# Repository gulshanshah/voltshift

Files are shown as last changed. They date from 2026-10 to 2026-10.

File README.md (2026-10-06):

# VoltShift

**Automatic voltage-stable line switcher.**

In many villages and homes the supply arrives unbalanced — some lines sit weak,
some sit high, and people walk over to the board and move the home supply to the
line that behaves. VoltShift does that switching automatically: it watches three
incoming lines, picks the one that is stable near 240 V, and drives a selector
switch onto it with a stepper motor — or to OFF when no line is safe.

## Repository layout

| Path | What it is |
| --- | --- |
| `pcb/` | KiCad 9 project — `voltshift.kicad_pro`, schematic, board and netlist |
| `firmware/` | ATmega328P firmware (bare-metal C, PlatformIO) |
| `media/` | Board renders, layer plots, schematic SVG and PDF |
| `docs/` | Schematic PDF and the ERC report |

## How it works

1. **Sensing** — three identical channels (R, Y, B), each a fusible 4R7 input
   resistor, three 150k 1 % series resistors stepping the AC line down, and a
   1N4007 rectifier turning it into a DC level the MCU can read. A 4k7 shunt,
   a 5.6 V zener and a 47 µF cap clamp and smooth that level.
2. **Isolation** — each channel feeds a PC817 optocoupler, so the mains domain
   stays galvanically separate from the logic domain; the opto output lands on
   an ATmega328P ADC input through a 10k pull-down.
3. **Decision** — the MCU samples all three inputs continuously, accepts only a
   line that reads stable near 240 V, and rejects anything too high or too low.
4. **Switching** — a 28BYJ-48 stepper driven by a ULN2003A turns the selector
   through four 45° positions: the healthy line, or OFF when nothing is in
   range.

The board keeps manual switching out of the equation — the home supply always
lands on the healthiest voltage.

## Hardware

- **MCU** — ATmega328P-PU @ 16 MHz, with ISP (2×3) and 5 V TTL UART headers
- **Drive** — ULN2003A → 28BYJ-48 stepper selector
- **Sensing** — 3× opto-isolated AC channels → ADC0/1/2
- **Power** — external 5 V DC input, ferrite-isolated AVCC
- **Board** — 170 × 100 mm, 2-layer, mains domain and logic domain split with
  ≥ 6 mm creepage between them and a ground pour kept to the logic side only
- **Status** — schematic and routed PCB complete, ERC clean (0 errors,
  0 warnings)

### Safety

This board handles **240 VAC mains**. Sense resistors must be rated for the
working voltage, creepage/clearance must be respected, and the board must not
be touched while powered. It is a prototype — validate it against your local
electrical rules before putting it anywhere near a real installation.

## Media

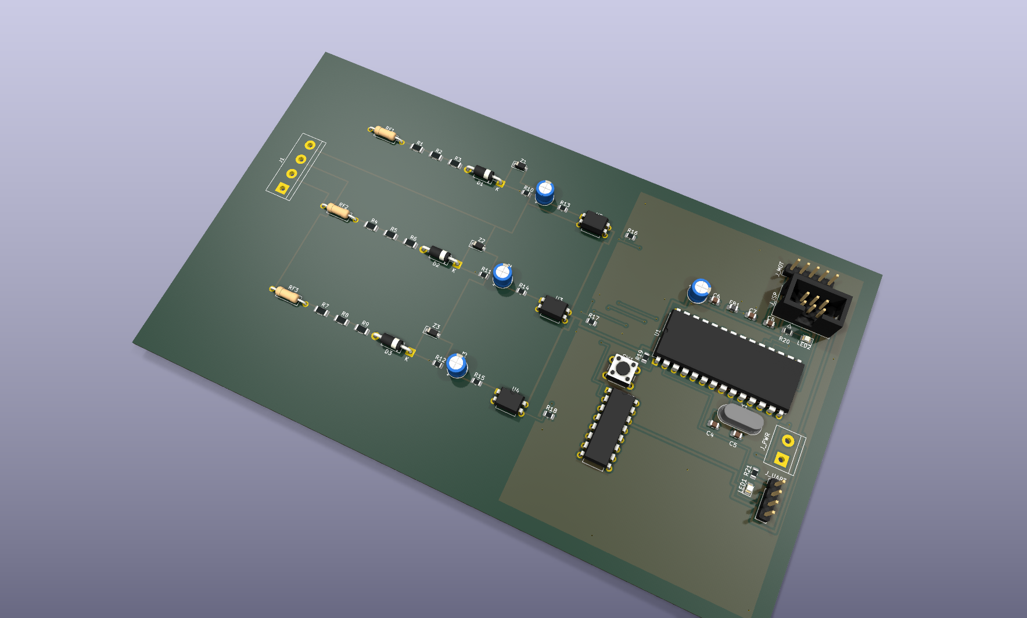
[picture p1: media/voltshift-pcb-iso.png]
VoltShift board render


| Top | Bottom |
| --- | --- |
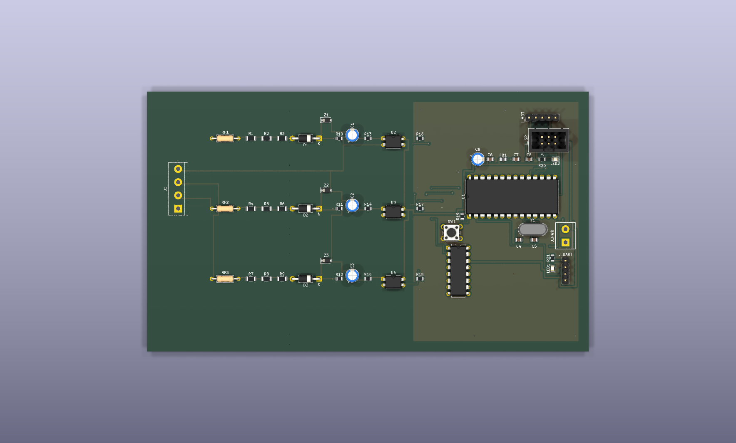
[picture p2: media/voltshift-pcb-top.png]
Board top
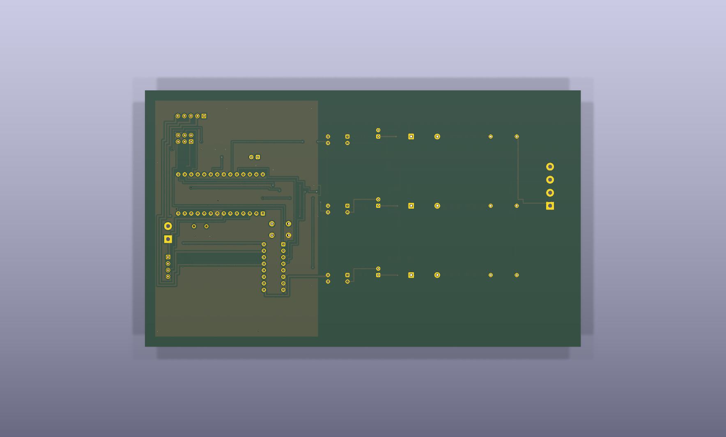
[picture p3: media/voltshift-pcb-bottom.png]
Board bottom
|  |  |

- [Schematic (SVG)](media/voltshift.svg) · [Schematic (PDF)](media/voltshift-schematic.pdf)
- [Top copper layout](media/voltshift-layout-top.svg) · [Bottom copper layout](media/voltshift-layout-bottom.svg)

## Firmware

The firmware lives in `firmware/` and runs directly on the ATmega328P — no Arduino framework, no communication, fully automatic, about 1.8 KB of flash.

```
firmware/include/config.h   # thresholds, calibration, pin map, timing
firmware/src/adc.c           # averaged ADC reads + counts-to-decivolts calibration
firmware/src/selector.c      # line validity, best-line choice, hysteresis
firmware/src/stepper.c       # half-step driver for the 28BYJ-48 selector
firmware/src/led.c           # status LED patterns
firmware/src/main.c          # 1 ms tick, sample/evaluate loop, watchdog
```

Every 10 ms each channel is averaged and converted to decivolts; every 100 ms a line is accepted only if it sits inside 205.0–255.0 V with under 2.0 V of ripple. The selector moves to the accepted line closest to 240 V, only after that line beats the held one by more than 3 V for four consecutive evaluations, and drops to OFF the moment the held line goes invalid. The status LED reports state: slow blink while starting up, solid on a line, fast blink on OFF or while the motor is moving.

Build and flash with PlatformIO:

```
cd firmware
pio run                     # builds firmware.elf / firmware.hex
pio run -t upload           # default programmer is usbasp (ISP)
```

Calibration is per-channel in `include/config.h` — `VS_CAL_OFFSET_*` and `VS_CAL_SPAN_*_PER_100V` map raw ADC counts to voltage; tune them against a known-good meter before trusting the decisions.

## Working on the design

Open `pcb/voltshift.kicad_pro` in KiCad 9 and edit the schematic and the board
directly. Run the Electrical Rules Checker after any change — the last check
came back clean (0 errors, 0 warnings).

Keep the two domains apart while editing: mains circuitry stays left of the
isolation gap, the ground pour belongs to the logic side only, and the 6 mm
creepage between them must survive any move. The exported schematic PDF and
the ERC report are in `docs/`.

## Status

Schematic and PCB are done and ERC-clean, and the firmware builds for the
ATmega328P. Next up: fab the board and build the first unit.

## License

MIT — see [LICENSE](LICENSE).

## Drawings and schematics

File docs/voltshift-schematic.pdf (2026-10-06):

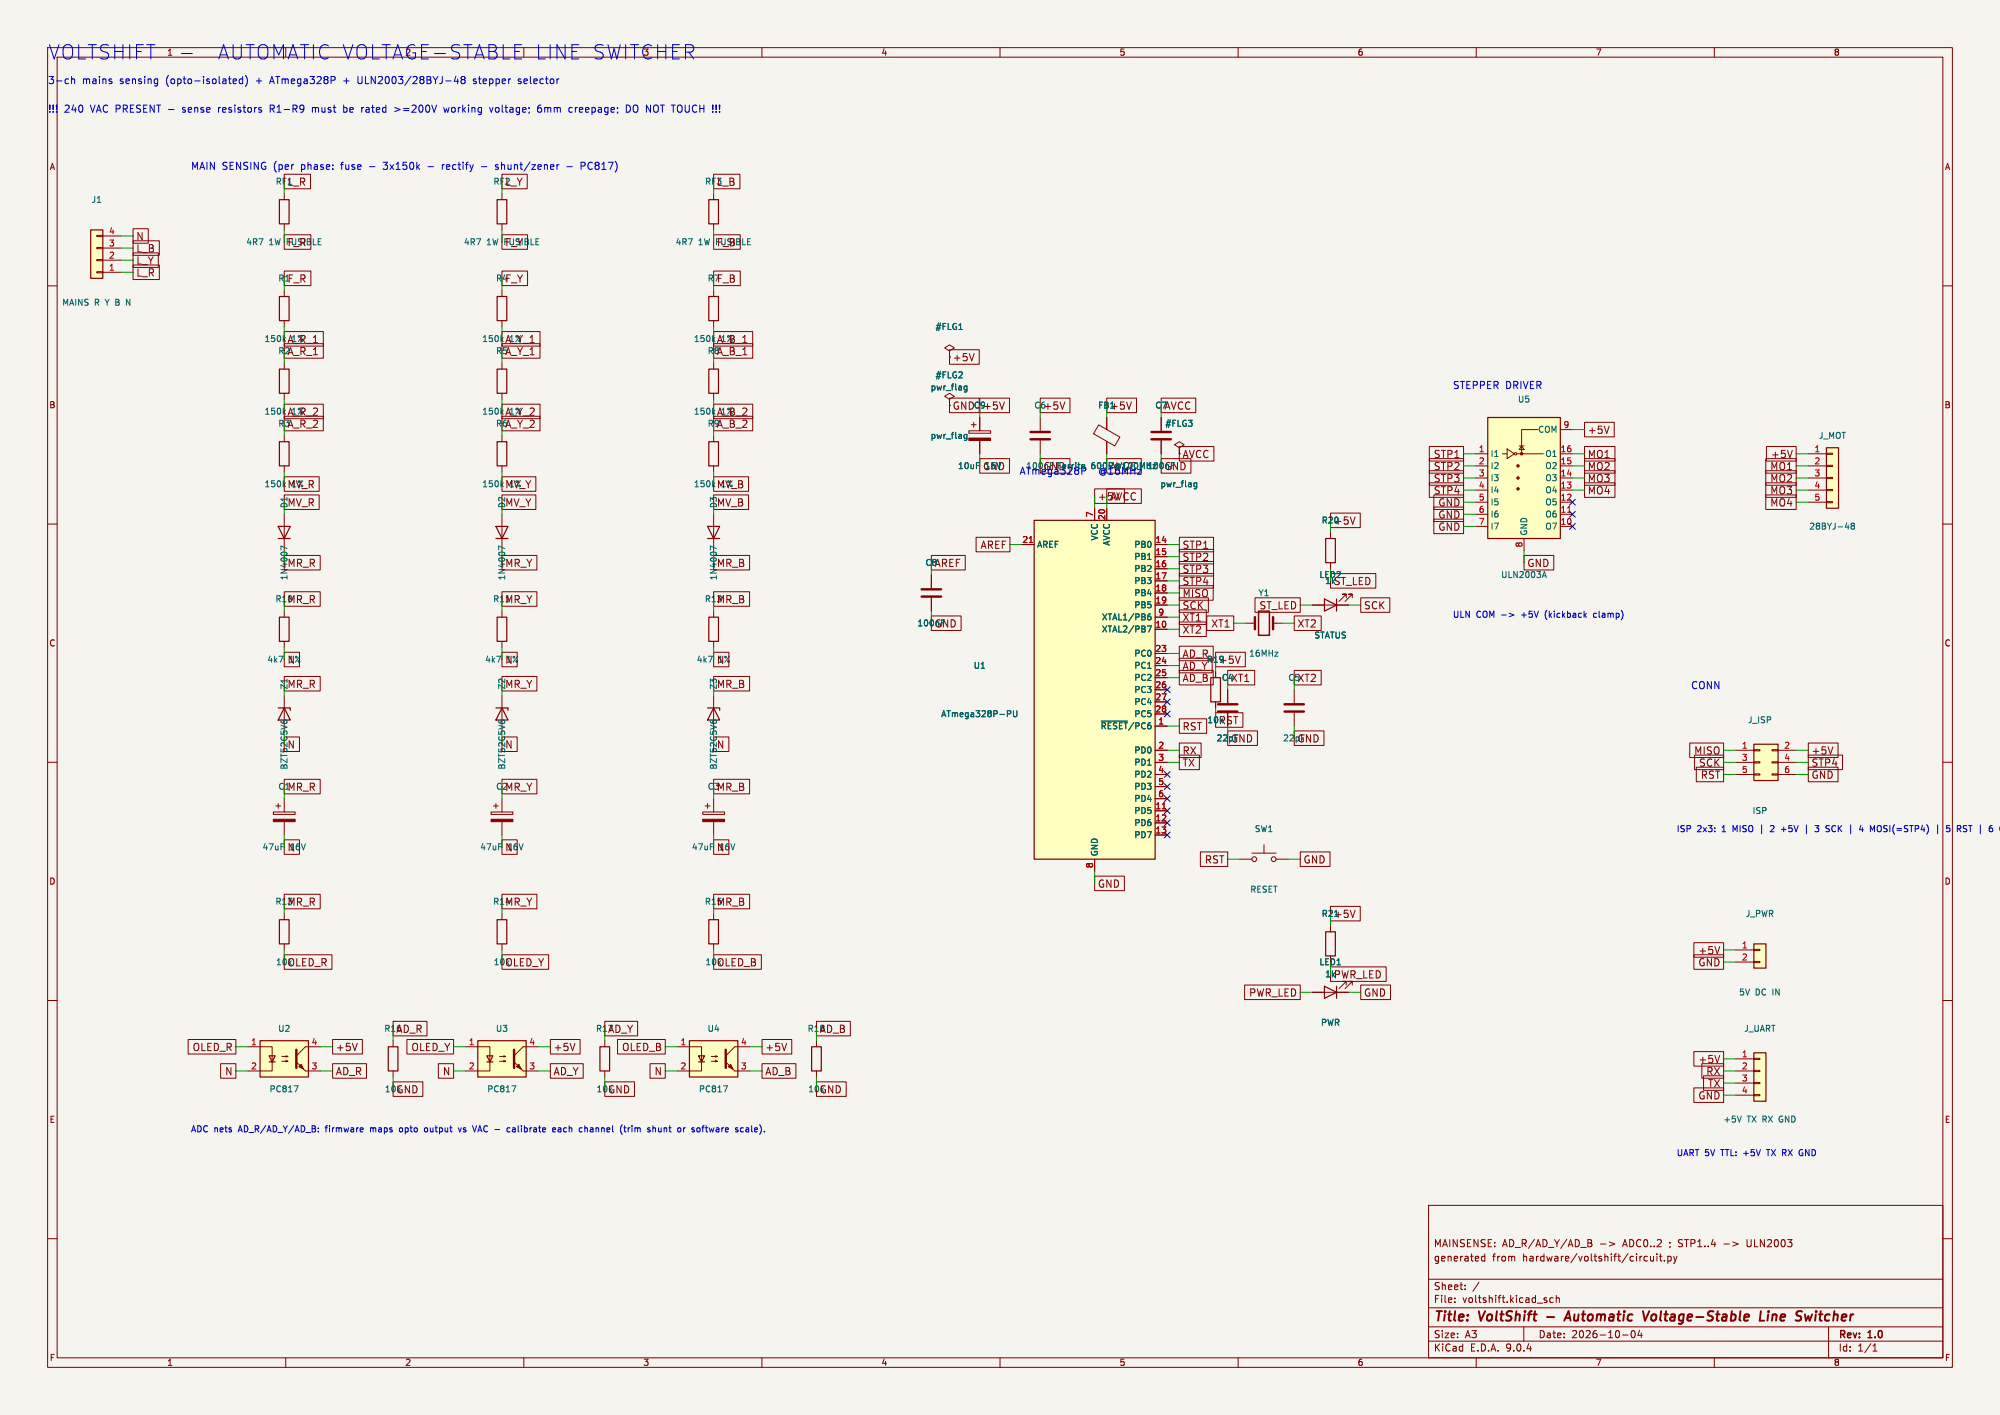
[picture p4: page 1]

UART 5V TTL: +5V TX RX GND

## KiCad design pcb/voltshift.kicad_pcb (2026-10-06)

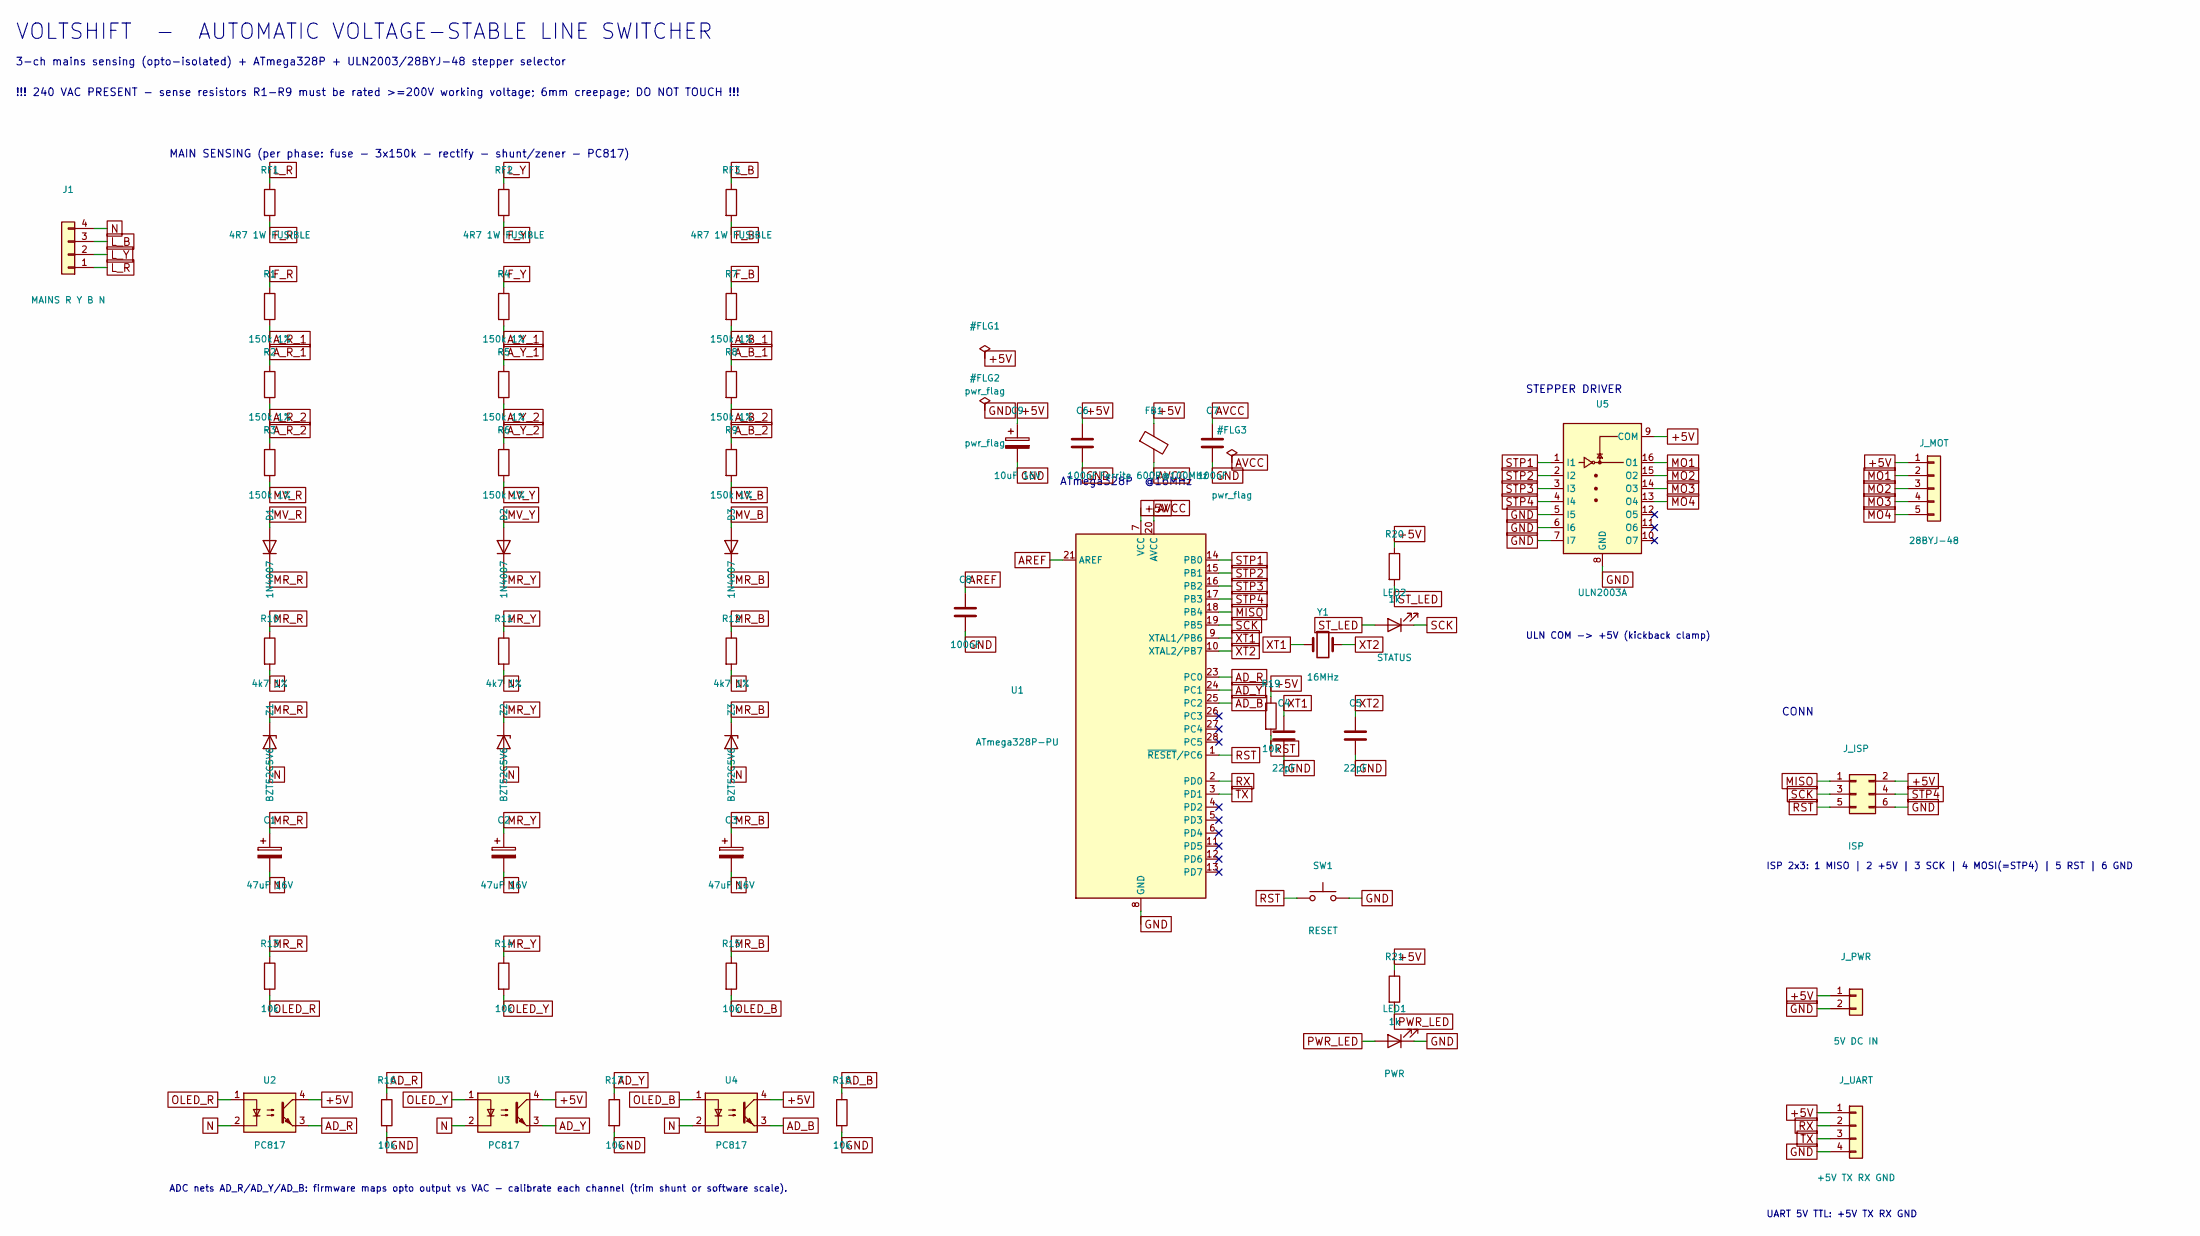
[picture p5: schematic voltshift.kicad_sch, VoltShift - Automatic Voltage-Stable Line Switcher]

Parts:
C1, C2, C3: 47uF 16V; CP_Radial_D5.0mm_P2.50mm
C4, C5: 22pF; C_0805_2012Metric
C6, C7, C8: 100nF; C_0805_2012Metric
C9: 10uF 16V; CP_Radial_D5.0mm_P2.50mm
D1, D2, D3: 1N4007; D_DO-41_SOD81_P10.16mm_Horizontal
FB1: Ferrite 600R@100MHz; L_0805_2012Metric
J1: MAINS R Y B N; TerminalBlock_bornier-4_P5.08mm
J_ISP: ISP; IDC-Header_2x03_P2.54mm_Vertical
J_MOT: 28BYJ-48; PinHeader_1x05_P2.54mm_Vertical
J_PWR: 5V DC IN; TerminalBlock_bornier-2_P5.08mm
J_UART: +5V TX RX GND; PinHeader_1x04_P2.54mm_Vertical
LED1: PWR; LED_0805_2012Metric
LED2: STATUS; LED_0805_2012Metric
R1, R2, R3, R4, R5, R6, R7, R8, R9: 150k 1%; R_1206_3216Metric
R10, R11, R12: 4k7 1%; R_0805_2012Metric
R13, R14, R15, R16, R17, R18, R19: 10k; R_0805_2012Metric
R20, R21: 1k; R_0805_2012Metric
RF1, RF2, RF3: 4R7 1W FUSIBLE; R_Axial_DIN0207_L6.3mm_D2.5mm_P10.16mm_Horizontal
SW1: RESET; SW_PUSH_6mm
U1: ATmega328P-PU; DIP-28_W15.24mm
U2, U3, U4: PC817; DIP-4_W7.62mm
U5: ULN2003A; DIP-16_W7.62mm
Y1: 16MHz; Crystal_HC49-4H_Vertical
Z1, Z2, Z3: BZT52C5V6; D_SOD-123

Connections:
+5V: C6.1, C9.1, FB1.1, J_ISP.2, J_MOT.1, J_PWR.1, J_UART.1, R19.1, R20.1, R21.1, U1.7 (VCC), U2.4, U3.4, U4.4, U5.9 (COM)
AD_B: R18.1, U1.25 (PC2), U4.3
AD_R: R16.1, U1.23 (PC0), U2.3
AD_Y: R17.1, U1.24 (PC1), U3.3
AREF: C8.1, U1.21 (AREF)
AVCC: C7.1, FB1.2, U1.20 (AVCC)
A_B_1: R7.2, R8.1
A_B_2: R8.2, R9.1
A_R_1: R1.2, R2.1
A_R_2: R2.2, R3.1
A_Y_1: R4.2, R5.1
A_Y_2: R5.2, R6.1
F_B: R7.1, RF3.2
F_R: R1.1, RF1.2
F_Y: R4.1, RF2.2
GND: C4.2, C5.2, C6.2, C7.2, C8.2, C9.2, J_ISP.6, J_PWR.2, J_UART.4, LED1.1 (K), R16.2, R17.2, R18.2, SW1.2, U1.8 (GND), U1.22 (GND), U5.5 (I5), U5.6 (I6), U5.7 (I7), U5.8 (GND)
L_B: J1.3, RF3.1
L_R: J1.1, RF1.1
L_Y: J1.2, RF2.1
MISO: J_ISP.1, U1.18 (PB4)
MO1: J_MOT.2, U5.16 (O1)
MO2: J_MOT.3, U5.15 (O2)
MO3: J_MOT.4, U5.14 (O3)
MO4: J_MOT.5, U5.13 (O4)
MR_B: C3.1, D3.1 (K), R12.1, R15.1, Z3.1 (K)
MR_R: C1.1, D1.1 (K), R10.1, R13.1, Z1.1 (K)
MR_Y: C2.1, D2.1 (K), R11.1, R14.1, Z2.1 (K)
MV_B: D3.2 (A), R9.2
MV_R: D1.2 (A), R3.2
MV_Y: D2.2 (A), R6.2
N: C1.2, C2.2, C3.2, J1.4, R10.2, R11.2, R12.2, U2.2, U3.2, U4.2, Z1.2 (A), Z2.2 (A), Z3.2 (A)
OLED_B: R15.2, U4.1
OLED_R: R13.2, U2.1
OLED_Y: R14.2, U3.1
PWR_LED: LED1.2 (A), R21.2
RST: J_ISP.5, R19.2, SW1.1, U1.1 (~RESET/PC6)
RX: J_UART.2, U1.2 (PD0)
SCK: J_ISP.3, LED2.1 (K), U1.19 (PB5)
STP1: U1.14 (PB0), U5.1 (I1)
STP2: U1.15 (PB1), U5.2 (I2)
STP3: U1.16 (PB2), U5.3 (I3)
STP4: J_ISP.4, U1.17 (PB3), U5.4 (I4)
ST_LED: LED2.2 (A), R20.2
TX: J_UART.3, U1.3 (PD1)
XT1: C4.1, U1.9 (XTAL1/PB6), Y1.1
XT2: C5.1, U1.10 (XTAL2/PB7), Y1.2

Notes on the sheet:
VOLTSHIFT - AUTOMATIC VOLTAGE-STABLE LINE SWITCHER
3-ch mains sensing (opto-isolated) + ATmega328P + ULN2003/28BYJ-48 stepper selector
!!! 240 VAC PRESENT - sense resistors R1-R9 must be rated >=200V working voltage; 6mm creepage; DO NOT TOUCH !!!
MAIN SENSING (per phase: fuse - 3x150k - rectify - shunt/zener - PC817)
ATmega328P @16MHz
STEPPER DRIVER
CONN
ADC nets AD_R/AD_Y/AD_B: firmware maps opto output vs VAC - calibrate each channel (trim shunt or software scale).
ISP 2x3: 1 MISO | 2 +5V | 3 SCK | 4 MOSI(=STP4) | 5 RST | 6 GND
UART 5V TTL: +5V TX RX GND
ULN COM -> +5V (kickback clamp)

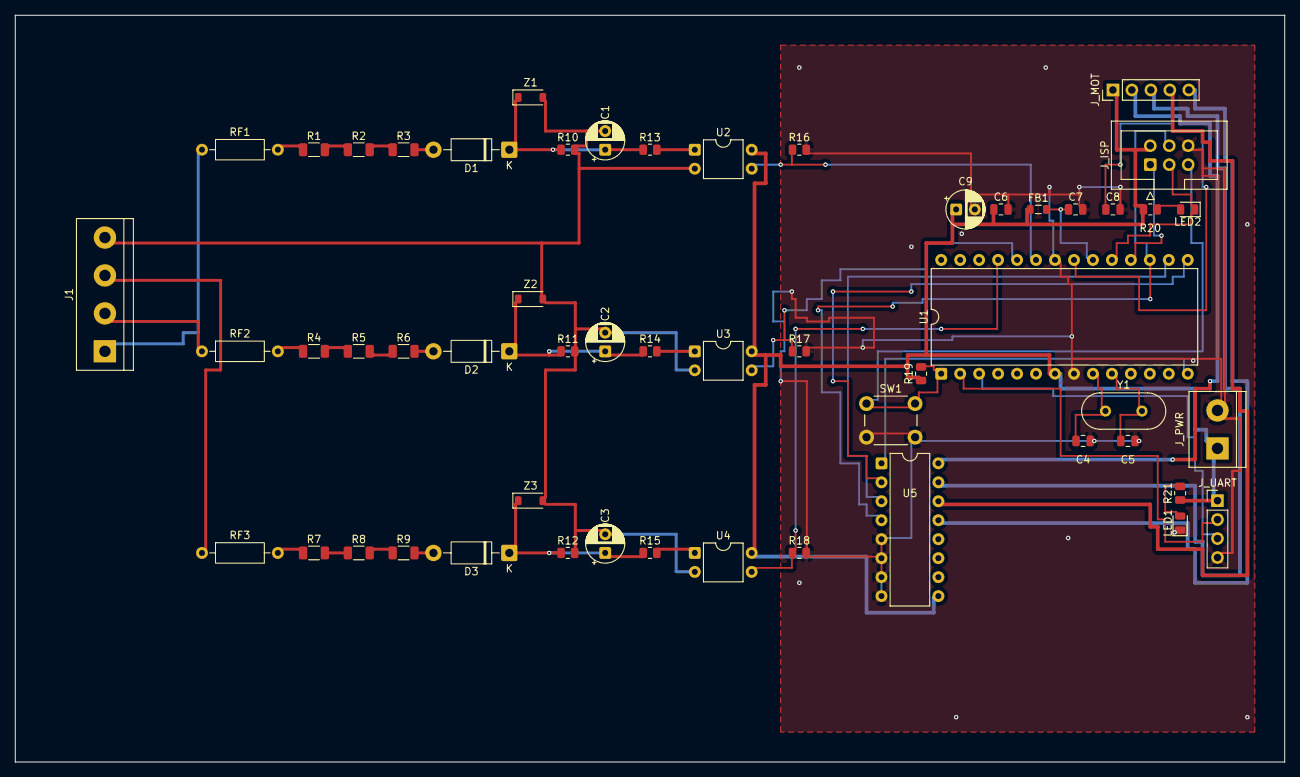
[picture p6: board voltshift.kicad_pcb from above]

Board: 2 copper layers, 170.0 x 100.0 mm, 54 parts (0 on the bottom side), 46 nets.

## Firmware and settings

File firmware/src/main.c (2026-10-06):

#include <avr/interrupt.h>
#include <avr/wdt.h>
#include <util/atomic.h>

#include "adc.h"
#include "config.h"
#include "led.h"
#include "selector.h"
#include "stepper.h"

static volatile uint32_t s_ms;

ISR(TIMER0_COMPA_vect)
{
    s_ms++;
}

static uint32_t millis(void)
{
    uint32_t value;

    ATOMIC_BLOCK(ATOMIC_RESTORESTATE)
    {
        value = s_ms;
    }
    return value;
}

static void timer_init(void)
{
    TCCR0A = _BV(WGM01);
    TCCR0B = _BV(CS01) | _BV(CS00);
    OCR0A = 249;
    TIMSK0 = _BV(OCIE0A);
}

static void select_mode(uint8_t startup)
{
    if (startup) {
        vs_led_set_mode(VS_LED_MODE_SLOW);
    } else if (vs_stepper_busy() || vs_selector_position() == VS_SEL_POS_OFF) {
        vs_led_set_mode(VS_LED_MODE_FAST);
    } else {
        vs_led_set_mode(VS_LED_MODE_ON);
    }
}

int main(void)
{
    uint32_t now;
    uint32_t last_sample = 0;
    uint32_t last_eval = 0;

    vs_adc_init();
    vs_selector_init();
    vs_stepper_init();
    vs_led_init();
    timer_init();
    wdt_enable(WDTO_1S);
    sei();

    for (;;) {
        now = millis();

        if ((now - last_sample) >= VS_SAMPLE_MS) {
            last_sample = now;
            vs_selector_sample();
        }

        if ((now - last_eval) >= VS_EVAL_MS) {
            uint8_t startup = now < VS_STARTUP_MS;

            last_eval = now;
            vs_selector_evaluate(startup);
            vs_stepper_goto(vs_selector_position());
            select_mode(startup);
        }

        vs_stepper_tick(now);
        vs_led_tick(now);
        wdt_reset();
    }
}

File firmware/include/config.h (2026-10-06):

#ifndef VS_CONFIG_H
#define VS_CONFIG_H

#include <stdint.h>

#define VS_CHANNEL_COUNT 3

#define VS_SAMPLE_MS 10
#define VS_EVAL_MS 100
#define VS_STARTUP_MS 2000
#define VS_SAMPLE_COUNT 16
#define VS_EMA_DIV 4

#define VS_TARGET_DV 2400
#define VS_MIN_DV 2050
#define VS_MAX_DV 2550
#define VS_MAX_RIPPLE_DV 20
#define VS_SWITCH_MARGIN_DV 30
#define VS_CONFIRM_EVALS 4

#define VS_CAL_OFFSET_R 10
#define VS_CAL_OFFSET_Y 10
#define VS_CAL_OFFSET_B 10

#define VS_CAL_SPAN_R_PER_100V 196
#define VS_CAL_SPAN_Y_PER_100V 196
#define VS_CAL_SPAN_B_PER_100V 196

#define VS_SEL_POS_R 0
#define VS_SEL_POS_Y 1
#define VS_SEL_POS_B 2
#define VS_SEL_POS_OFF 3
#define VS_SEL_POS_COUNT 4
#define VS_BOOT_POSITION VS_SEL_POS_OFF

#define VS_HALF_STEPS_PER_POS 64
#define VS_STEP_INTERVAL_MS 2
#define VS_STEP_HOLD_POWER 1

#define VS_STEPPER_PORT PORTB
#define VS_STEPPER_DDR DDRB
#define VS_STEPPER_MASK 0x0FU

#define VS_LED_PORT PORTB
#define VS_LED_DDR DDRB
#define VS_LED_BIT 5
#define VS_LED_ACTIVE_LOW 1

#endif

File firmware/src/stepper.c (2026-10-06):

#include "stepper.h"
#include "config.h"

#include <avr/io.h>

static const uint8_t s_pattern[8] = { 0x01U, 0x03U, 0x02U, 0x06U, 0x04U, 0x0CU, 0x08U, 0x09U };

static int16_t s_abs_step;
static int16_t s_remaining;
static uint8_t s_target;
static uint8_t s_step_index;
static uint32_t s_next_ms;

static void coil_write(uint8_t index)
{
    uint8_t value = s_pattern[index & 0x07U];

#if VS_STEP_HOLD_POWER == 0
    if (s_remaining == 0) {
        value = 0;
    }
#endif

    VS_STEPPER_DDR |= VS_STEPPER_MASK;
    VS_STEPPER_PORT = (uint8_t)((VS_STEPPER_PORT & (uint8_t)~VS_STEPPER_MASK) | value);
}

void vs_stepper_init(void)
{
    s_target = VS_BOOT_POSITION;
    s_abs_step = (int16_t)(VS_BOOT_POSITION * VS_HALF_STEPS_PER_POS);
    s_remaining = 0;
    s_step_index = 0;
    s_next_ms = 0;

    VS_STEPPER_DDR |= VS_STEPPER_MASK;
    VS_STEPPER_PORT &= (uint8_t)~VS_STEPPER_MASK;
#if VS_STEP_HOLD_POWER
    coil_write(s_step_index);
#endif
}

void vs_stepper_goto(uint8_t position)
{
    int16_t target;

    if (position >= VS_SEL_POS_COUNT) {
        position = VS_SEL_POS_OFF;
    }

    target = (int16_t)(position * VS_HALF_STEPS_PER_POS);
    s_target = position;
    s_remaining = (int16_t)(target - s_abs_step);
}

void vs_stepper_tick(uint32_t now)
{
    int8_t dir;

    if (s_remaining == 0) {
#if VS_STEP_HOLD_POWER
        coil_write(s_step_index);
#endif
        return;
    }

    if ((int32_t)(now - s_next_ms) < 0) {
        return;
    }

    dir = s_remaining > 0 ? 1 : -1;
    s_step_index = (uint8_t)((s_step_index + dir + 8) & 0x07);
    s_abs_step = (int16_t)(s_abs_step + dir);
    s_remaining = (int16_t)(s_remaining - dir);
    coil_write(s_step_index);
    s_next_ms = now + VS_STEP_INTERVAL_MS;
}

uint8_t vs_stepper_busy(void)
{
    return s_remaining != 0;
}

uint8_t vs_stepper_position(void)
{
    return s_target;
}
